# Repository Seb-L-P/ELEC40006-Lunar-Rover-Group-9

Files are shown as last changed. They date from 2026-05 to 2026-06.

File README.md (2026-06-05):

# EEELunarRover - Group 9

ELEC40006 Electronics Design Project. A remotely operated lunar rover that drives across an arena and classifies rocks by their age and type.

## Repository layout

| Path | What it is |
| --- | --- |
| `rover_firmware/` | Metro M0 firmware: WiFi HTTP server, motor control, sensor hooks |
| `UI/` | Browser-based operator console (HTML/CSS/JS) plus a mock rover server |
| `hardware/` | Component datasheets, the pin map, and the **[bill of materials](hardware/BOM.md)** |
| `mech/` | **[Rover layout, 3D-printed sensor mounts, and what to order](mech/README.md)** |
| `CONTROLLER_PLAN.md` | HTTP API contract and controller subsystem design |
| `PROJECT_SUMMARY.md` | Project brief, objectives, constraints, rock classification |

The operator control and firmware are built and hardware-tested. The four analogue sensor subsystems (radio, infrared, ultrasound, magnetic) are in progress by other group members and plug into the firmware through its `readX()` hooks.

## How it works

The operator runs the console in a browser. It talks to the rover over WiFi using a small HTTP API:

```text
Operator browser  <--- WiFi / HTTP --->  Metro M0 firmware
   (UI/)                                  (rover_firmware/)
                                               |
                                       motors and sensors
```

The firmware exposes five endpoints (`/info`, `/status`, `/drive`, `/stop`, `/scan`). The UI polls `/status` for telemetry, sends `/drive` to move the rover, and `/scan` to classify a rock. The full contract is in `CONTROLLER_PLAN.md`.

## Quick start

### Operator console (no hardware needed)

```bash
cd UI
python3 mock_server.py
```

Open <http://localhost:8080/>. The mock server simulates a rover so the UI can be developed and tested without any hardware.

### Firmware

Open `rover_firmware/` in VS Code with the PlatformIO extension, or from the command line:

```bash
cd rover_firmware
pio run            # build
pio run -t upload  # flash a connected Metro M0
```

## Status

| Part | State |
| --- | --- |
| Firmware build | Compiles; runs on real Metro M0 hardware |
| HTTP API | All five endpoints verified over WiFi |
| Drive control | Verified end to end, operator console to motors |
| Operator UI | Working; gamepad, keyboard and on-screen control |
| Sensors | Stubbed; awaiting the four analogue subsystems |

See `rover_firmware/TEST_LOG.md` for the detailed hardware test record.

## Rock classification

The rover identifies one of four rock types from three measurements:

| Type | Infrared rate | Ultrasound | Magnet |
| --- | --- | --- | --- |
| Basaltoid | high (~547/s) | present | down |
| Gravion | low (~312/s) | absent | down |
| Regolix | low (~312/s) | present | up |
| Lunarite | high (~547/s) | absent | up |

It also reads the rock's age, transmitted by radio. Full detail in `PROJECT_SUMMARY.md`.

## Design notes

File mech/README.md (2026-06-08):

# Mechanical & sensor layout — rover design, 3D prints, and parts to order

This folder is the **mechanical/sensor design package**: where every sensor,
the battery and the boards sit on the rover, the 3D-printable mounts that hold
them, and **exactly what we need to order** (with supplier links and prices).

- 📐 Full design rationale + diagrams → **[`rover_layout.md`](rover_layout.md)**
- 🧾 Full bill of materials + ordering rules → **[`../hardware/BOM.md`](../hardware/BOM.md)**
- 🖨️ How to print the parts → **[`print/README.md`](print/README.md)**
- 🧱 Alternative **stacked-deck chassis** concept (two decks on pillars + coil ring) → **[`stacked_deck/`](stacked_deck/README.md)**

## The whole rover

| Isometric | Top-down (layout) |
|---|---|
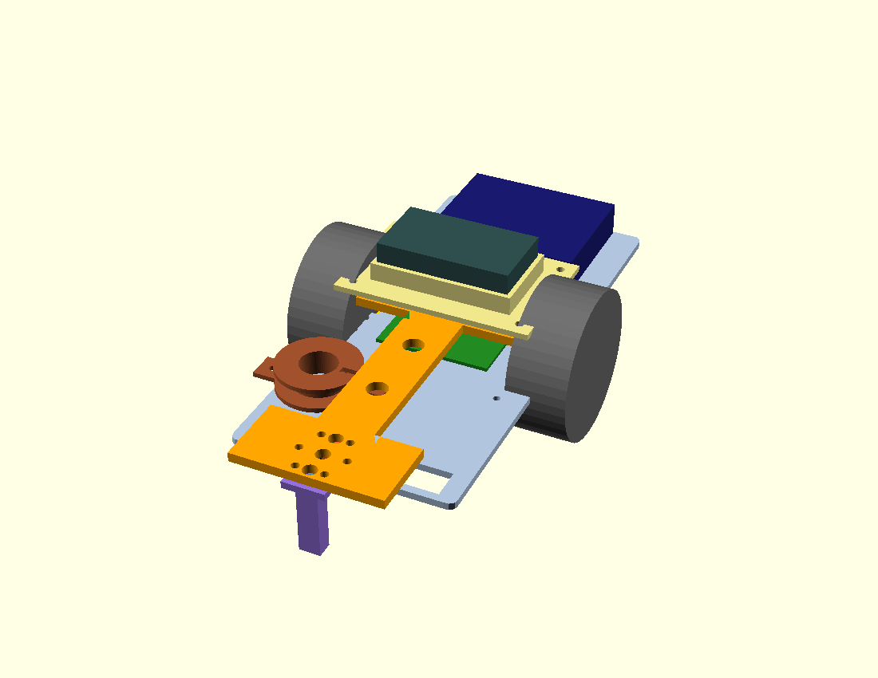
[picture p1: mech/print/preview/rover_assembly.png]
rover assembly
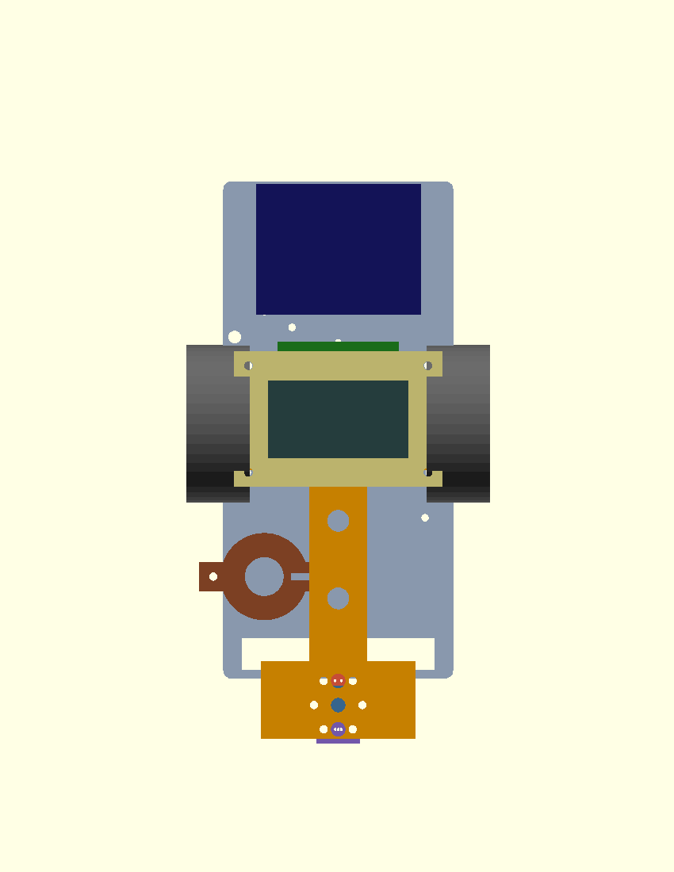
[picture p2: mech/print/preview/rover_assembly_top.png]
rover top view
|  |  |

*The chassis, wheels, battery and Metro are representative blocks; the boom,
sensor housings and battery tray are the actual printable parts. Open
`print/rover_assembly.scad` in OpenSCAD (press F5) to spin it around.*

## Design in brief

The EEEBug is a **centre-axle** rover (it pivots about the middle), so:

- **Sensors go on a front boom**, as far as possible from the motor magnets and
  PWM noise — the **Hall sensor** especially, on a long pod that reaches near the
  floor to read the magnet inside the rock.
- **IR, ultrasound and Hall** face **down** in a line at the boom tip; the rover
  noses up to a rock and scans it.
- **Radio antenna coil** sits low at the **front-left**, off the boom centre-line.
- **Battery (4×AA, ~100 g)** sits on a tray **over the axle** — balances the
  pivot, loads the wheels for traction, and keeps its noise away from the weak
  analogue front-ends.
- **Metro M0 + WiFi** stay at the **rear**.
- Estimated total mass **≈ 503 g** (limit 750 g); design spend **≈ £20–51**
  (budget ~£55). See the layout doc for the full weight budget and rationale.

## What's in here

| File | What it is |
|---|---|
| [`rover_layout.md`](rover_layout.md) | Master design doc: layout, physics rationale, weight budget, keep-out zones, hole mapping, assembly order |
| [`../hardware/BOM.md`](../hardware/BOM.md) | Full parts list with supplier order codes, prices, dimensions, ordering rules |
| [`print/`](print/README.md) | Parametric OpenSCAD parts (`.scad`), rendered `.stl`, preview `.png`, and `render.sh` |
| `print/rover_assembly.scad` | The whole-rover 3D model (visualisation) |
| `print/chassis.scad` | Exact EEEBug outline auto-generated from `chassis.svg` |
| `chassis.svg` / `.dxf` / `.pdf` | Original EEEBug V3.1 chassis CAD (laser-cut source) |
| [`CHASSIS_CAD.md`](CHASSIS_CAD.md) | Notes on the chassis CAD formats / laser-cut conventions |

Printable parts: `boom`, `ir_shroud`, `ultrasound_clamp`, `hall_pod`,
`antenna_bobbin`, `perfboard_carrier`, `battery_tray`. All print flat in PLA,
no supports; largest is the boom at 86 × 127 mm (well inside the 200 mm printer).

---

## 🛒 Parts to order

> **Orders go through the [EEE Stores order form](https://www.imperial.ac.uk/electrical-engineering/internal/stores/)** via our nominated approver.
> Allowed suppliers only (RS / OneCall = Farnell & CPC / Rapid / EED Stores).
>
> ⚠️ **Prices are estimates** — the supplier pages block automated price
> reads, so **click the link and confirm the live price on the order form
> before ordering.** Order codes and dimensions are datasheet/catalogue-verified.
>
> 🚫 Per the brief: **do not order batteries, glue/chemicals, or tools.** The AA
> cells, magnet, Metro, WiFi shield, motor driver and breadboard are in the kit.
> Everything below is **through-hole** (no surface-mount).

### Group A — specialist sensor parts (order from RS / Farnell / CPC)

| Part | For | Supplier · code | Qty | Unit (est) | Line (est) |
|---|---|---|---|---|---|
| Murata **MA40S4R** 40 kHz Rx | ultrasound | [CPC SN36522](https://cpc.farnell.com/murata/ma40s4r/sensor-ultrasonic-0-2-4m-rx/dp/SN36522) | 2 | £2.50 | £5.00 |
| Honeywell **SS49E** Hall | magnetic | [RS 236-2760](https://uk.rs-online.com/web/p/hall-effect-sensors/2362760) | 2 | £1.50 | £3.00 |
| OSRAM **SFH 300** phototransistor | infrared | [Farnell 2981724](https://uk.farnell.com/osram-opto-semiconductors/sfh-300/photo-trans-npn-880nm-radial-leaded/dp/2981724) | 2 | £0.60 | £1.20 |
| Microchip **MCP6292-E/P** dual op-amp (DIP-8) | IR/radio/US amps | [Farnell 1439466](https://uk.farnell.com/microchip/mcp6292-e-p/op-amp-10mhz-dual-pdip8-6292/dp/1439466) | 3 | £1.00 | £3.00 |
| Roth **RE016-LF** perfboard (68.6×68 mm) | large board | [RS 897-1402](https://uk.rs-online.com/web/p/matrix-boards/8971402) | 1 | £3.39 | £3.39 |
| Roth **RE015-LF** perfboard (40.5×40 mm) | small boards | [RS 897-1408](https://uk.rs-online.com/web/p/matrix-boards/8971408) | 2 | £1.63 | £3.26 |
| | | | | **Subtotal A** | **≈ £18.85** |

### Group B — commodity parts (try EED Stores dept stock first, else order)

| Part | For | Supplier · code | Qty | Unit (est) | Line (est) |
|---|---|---|---|---|---|
| M3 nylon hex standoff, M-F, 15 mm (pk 100) | mount boom/tray | [Rapid 52-4352](https://www.rapidonline.com/r-tech-524352-nylon-hexagonal-m3-m-f-spacers-15mm-pack-of-100-52-4352) | 1 | £7.63 | £7.63 |
| M3 steel pan screw, 6 mm (pk 100) | board/module screws | [Rapid 33-7089](https://www.rapidonline.com/r-tech-337089-pozi-pan-head-a2-stainless-steel-screws-m3-6mm-pack-of-100-33-7089) | 1 | £4.59 | £4.59 |
| M3 steel hex nut (pk 100) | lock standoffs | [Rapid 33-7173](https://www.rapidonline.com/r-tech-337173-a2-stainless-steel-hex-nut-m3-pack-of-100-33-7173) | 1 | £3.89 | £3.89 |
| Enamelled copper wire 0.28 mm (solderable) | 89 kHz antenna coil | [RS 779-0700](https://uk.rs-online.com/web/p/copper-wire/7790700) | 1 | £8–12 | £10.00 |
| 0.1″ pin headers + M-M jumper leads | inter-board wiring | CPC / dept stock | – | £3.00 | £3.00 |
| Resistors + capacitors (IR/radio/US front-ends) | front-ends | dept stock / kit | – | £3.00 | £3.00 |
| | | | | **Subtotal B** | **≈ £32.11** |

**Budget:** ≈ **£51 if everything is ordered**, or **≈ £20–25** if Group B comes
from EED Stores dept stock — both inside the ~£55 left. See
[`../hardware/BOM.md`](../hardware/BOM.md) for spare quantities, the SS495A (5 V)
Hall alternative, and the full ordering-rules checklist.

---

## See / build it

- **3D model:** open `print/rover_assembly.scad` in [OpenSCAD](https://openscad.org) → press **F5** (drag to rotate). Or just look at the PNGs in `print/preview/`.
- **Print:** `cd mech/print && ./render.sh` regenerates all STLs; print PLA, 0.2 mm layers, 4 perimeters, 25 % infill, no supports.
- **Edit a dimension:** every part is parametric — change the variable at the top of the relevant `.scad` (e.g. battery-pocket size in `battery_tray.scad`).

*Questions on this design → ask in the group chat or open an issue.*

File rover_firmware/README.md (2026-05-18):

# EEELunarRover Firmware

Metro M0 Express + WINC1500 WiFi shield. Implements the HTTP API contract in `../CONTROLLER_PLAN.md`, drives the H-bridge motor module, and exposes stubs that each sensor subsystem owner replaces with real hardware code.

## Build and flash

Two routes, both target the same `src/main.cpp`.

### PlatformIO (recommended)

1. Install [VS Code](https://code.visualstudio.com/) and the [PlatformIO extension](https://platformio.org/install/ide?install=vscode).
2. Open this `rover_firmware/` folder.
3. Plug the Metro M0 into the laptop via USB.
4. Click the **Build** (✓) and then **Upload** (→) buttons in the bottom toolbar, or run from the integrated terminal:

   ```bash
   pio run                 # build
   pio run -t upload       # flash
   pio device monitor      # serial monitor at 9600 baud
   ```

PlatformIO will download the SAMD platform, ArduinoJson, and WiFiWebServer on the first build.

### Arduino IDE

Copy the contents of `src/main.cpp` into a sketch called `EEELunarRover.ino` and install:

- Board support: follow [Adafruit's Metro M0 setup guide](https://learn.adafruit.com/adafruit-metro-m0-express/arduino-ide-setup).
- Libraries (via Library Manager): **WiFiWebServer** (Khoi Hoang) and **ArduinoJson** (Benoit Blanchon, v6.x).

## What to change before first flash

Open `src/main.cpp` and review the **Configuration** block near the top:

| Constant | Default | Set to |
| --- | --- | --- |
| `ssid` / `pass` | `EEERover` / `exhibition` | Lab WiFi credentials. Override if testing on a hotspot. |
| `groupNumber` | `0` | Your group number. This sets a static IP of `192.168.0.<groupNumber+1>` on the lab network. |
| `LEFT_DIR_PIN`, `LEFT_PWM_PIN`, `RIGHT_DIR_PIN`, `RIGHT_PWM_PIN` | `12`, `6`, `4`, `9` | Set to the current dual H-bridge wiring (see `../hardware/pin_map.md`). Change only if the rover is rewired. **Avoid 5, 7, 10** (reserved by the WiFi shield). |
| `DRIVE_WATCHDOG_MS` | `500` | Time without a `/drive` heartbeat before motors auto-stop. Don't reduce below the UI heartbeat interval (150 ms) plus margin. |
| `SCAN_DURATION_MS` | `600` | Window over which `/scan` integrates measurements. Increase to count more IR pulses for better Poisson rate discrimination. |

## Verifying it works

After flashing, open the serial monitor at 9600 baud. You should see:

```text
EEELunarRover firmware starting
Connecting to EEERover
.....
IP: 192.168.0.<your_ip>
HTTP server running
```

Then on a laptop or phone on the **same WiFi network**:

```bash
# Replace the IP with whatever the serial monitor reported
curl http://192.168.0.1/info
curl http://192.168.0.1/status
curl "http://192.168.0.1/drive?l=128&r=-64"
curl http://192.168.0.1/stop
curl http://192.168.0.1/scan
```

Each should return a JSON document. The onboard LED reports status: **fast blink** while WiFi is down, **solid** when `/drive` is driving the motors, **off** when idle and connected. So even with no serial cable attached, a fast-blinking LED means "not on WiFi" and a solid LED means "receiving drive commands".

To connect the operator UI, open it with the rover's IP in the API query string:

```
http://localhost:8080/?api=http://192.168.0.<groupNumber+1>
```

(The mock server at `../UI/mock_server.py` is no longer needed once real firmware is running, but you can still serve the UI files with it if you prefer.)

## Plugging in real sensors

Inside `src/main.cpp`, find the section labelled **Sensor stubs (to be replaced)**. Each function returns fake but plausible data so the UI runs end-to-end before any analogue hardware exists.

When a sensor subsystem is ready, replace the body of the corresponding function while keeping its return shape identical:

| Function | Owner | Returns |
| --- | --- | --- |
| `readAge()` | Radio subsystem | `{ "#NNN", valid }` |
| `readIR()` | IR subsystem | `{ pulses-per-second, valid }` |
| `readUltrasound()` | Ultrasound subsystem | `{ present (bool), valid }` |
| `readMagnet()` | Magnet subsystem | `{ "up" \| "down", valid }` |
| `readBatteryMv()` | Anyone | int millivolts |

Each sensor owner should be able to develop their function in isolation, hand it over, and have it Just Work without touching the routing or JSON code.

## Architecture notes

- **Why a 500 ms watchdog.** If WiFi drops while a drive key is held, the motors would keep running until the laptop reconnected. The watchdog auto-stops the rover instead. The UI sends `/drive` heartbeats every 150 ms while a key is pressed, which is well inside the watchdog window.
- **Why JSON for `/status`.** Slightly fatter on the wire than a delimited string but trivially parsed in the browser and self-describing for debugging.
- **Why `/scan` blocks.** Single-threaded server, simplest implementation. The UI shows a "Scanning..." button state during the ~600 ms scan and resumes polling afterwards. A more advanced version could integrate IR pulse counts asynchronously.
- **Why classification is not on the rover.** The UI does the table lookup. Keeps the firmware simpler and lets us tweak rules without re-flashing. See section 4.1 of `../CONTROLLER_PLAN.md`.
- **Why CORS headers.** The UI is hosted on the operator's laptop during development, which is a different origin from the rover's IP. The `Access-Control-Allow-Origin: *` header on every JSON response lets the browser accept the response.
- **Why the WiFi connect is bounded and retried.** The starter sketch loops on `WiFi.begin()` forever; a bad password or absent network hangs the board silently. This firmware tries a bounded number of times, then starts anyway and keeps retrying from `loop()`. If the link drops mid-demo it stops the motors and reconnects on its own.
- **Why JSON serialises into a fixed buffer.** Building a heap `String` per request would fragment the 32 KB RAM over a long run. A fixed stack buffer avoids that.

## Files

```text
rover_firmware/
├── platformio.ini       PlatformIO project config + library deps
├── README.md            this file
└── src/
    └── main.cpp         all the firmware in one file, sectioned by purpose
```

The single-file structure is intentional. The codebase is small enough that splitting into headers would add navigation overhead without saving lines. As each sensor owner adds non-trivial logic, they may choose to factor their code into `src/sensor_<name>.cpp` and an `include/sensor_<name>.h` - PlatformIO will pick those up automatically.

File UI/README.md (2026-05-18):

# Operator UI

Static HTML/JS/CSS operator interface for the EEELunarRover. Talks to the rover over HTTP per the contract in `../CONTROLLER_PLAN.md`.

## Run it locally (mock mode)

The mock server hosts the UI and a fake rover API on the same port, so no CORS pain.

```bash
cd UI
python3 mock_server.py
```

Then open <http://localhost:8080/> in a browser. The simulated rock changes every time you press **Scan rock**.

Requires Python 3.7+. No pip install needed, only the standard library.

## Run against a real rover

Open the page against the rover's HTTP server. Two ways:

1. **UI served by the rover firmware** (if the embedded lead implements `GET /` to return this `index.html`): just visit `http://192.168.0.<groupNumber+1>/`.
2. **UI hosted on your laptop, API on the rover:** open `http://localhost:8080/?api=http://192.168.0.<groupNumber+1>` so the page fetches from the rover instead of localhost. Requires the firmware to send `Access-Control-Allow-Origin: *` headers, or visit the page directly from the rover.

## Controls

The console accepts three input methods, all live at once:

### Gamepad (primary)

Pair an Xbox (or any standard) controller with the laptop over USB or Bluetooth. The browser detects it automatically via the Gamepad API; the header shows "Gamepad connected".

| Control | Action |
| --- | --- |
| Left stick | Drive (proportional speed and turn) |
| Controller D-pad | Drive (digital) |
| A button | Scan rock |
| B button | Stop |

The left stick wins whenever it is moved; release it and keyboard/on-screen control takes over.

### Keyboard and on-screen D-pad (fallback)

Always available, including if the gamepad disconnects mid-run.

| Key | Action |
| --- | --- |
| `W` / `↑` | Forward (hold) |
| `S` / `↓` | Reverse (hold) |
| `A` / `←` | Turn left (hold) |
| `D` / `→` | Turn right (hold) |
| `Space` / `X` / `Esc` | Stop |

The on-screen mini D-pad in the Control panel does the same thing for touch/mouse.

Switching tab or backgrounding the page auto-sends `/stop` for safety.

## Files

| File | Purpose |
| --- | --- |
| `index.html` | Page structure |
| `styles.css` | Layout and theme |
| `app.js` | Input handling, polling, classification, scan, saved readings |
| `mock_server.py` | Local rover stand-in implementing the same HTTP API |

## Classification logic

Lives in `app.js` (`classify()`) as a four-row lookup against the table in the project brief:

| IR rate (Hz) | Ultrasound | Magnet | Type |
| --- | --- | --- | --- |
| ≥ 430 (≈547) | present | down | Basaltoid |
| < 430 (≈312) | absent | down | Gravion |
| < 430 (≈312) | present | up | Regolix |
| ≥ 430 (≈547) | absent | up | Lunarite |

The 430 Hz threshold is the midpoint between the two Poisson rates (312 and 547 s⁻¹). The brief warns to expect small deviations, hence the wide margin.

## What this UI assumes from the firmware

- `GET /info` returns JSON with `group`, `ip`, `fw_version`.
- `GET /status` returns the JSON shape used by `renderStatus()` in `app.js`.
- `GET /drive?l=<int>&r=<int>` accepts signed PWM values in `[-255, 255]`.
- `GET /stop` zeroes both motors immediately.
- `GET /scan` runs a measurement cycle (≤ ~1 s) and returns age + raw sensor readings.
- A **500 ms watchdog** auto-zeros motors if `/drive` stops being called. The UI re-sends the held command every 150 ms to stay inside the watchdog.

All of this is locked in `../CONTROLLER_PLAN.md` and must be agreed with the embedded lead before code on either side hardens.

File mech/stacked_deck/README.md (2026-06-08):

# Stacked-deck chassis + coil support

An alternative chassis concept (inspired by the reference rover): **two
rectangular decks with the board's hole pattern, stacked on 4 corner pillars**,
plus a **braced coil ring + sensor tray** that screws onto a deck.

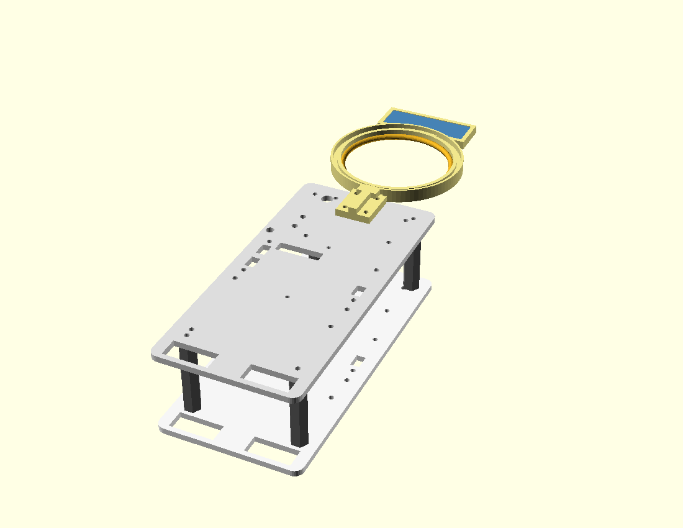
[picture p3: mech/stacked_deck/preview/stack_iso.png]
assembly


## One STL per component

| STL | Print qty | Size | Notes |
|---|---|---|---|
| `stl/deck_half_A.stl` | ×2 | ~122 × 95 mm | front half + bottom overlap ledge (motor slots) |
| `stl/deck_half_B.stl` | ×2 | ~102 × 95 mm | rear half + top overlap ledge (**print upside-down**) |
| `stl/pillar.stl` | ×4 | Ø10 × 50 mm | corner stacking pillar (~5 cm deck gap) |
| `stl/coil_support.stl` | ×1 | ~127 × 91 mm | braced ring (coil) + perfboard tray |
| `stl/deck_full.stl` | — | 204 × 95 mm | **reference/viewing only — too long to print whole** |

A full deck is **204 mm**, longer than the 200 mm printer, so each deck prints
as **half A + half B** (both inside the ~15–18 cm target) that **overlap** at a
half-lap and bolt together. Two identical decks → **either board can be on top**.

## How the parts connect

| Pillar ↔ decks | Half A ↔ half B |
|---|---|
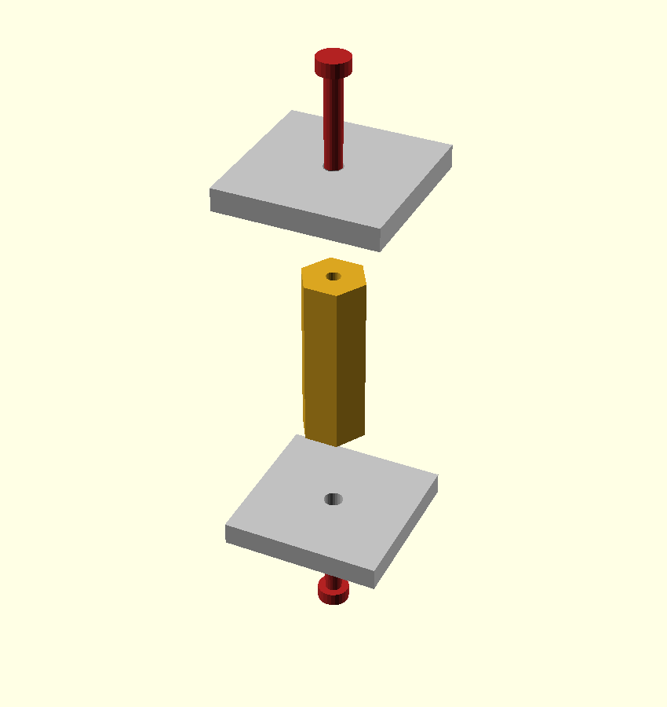
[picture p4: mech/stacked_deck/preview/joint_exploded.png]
pillar joint
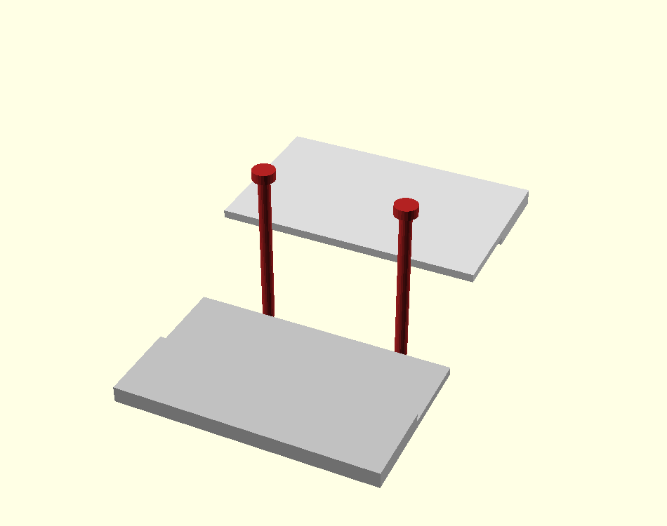
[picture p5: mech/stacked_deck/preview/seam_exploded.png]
seam joint
|  |  |
| A short M3 screw through each deck's corner hole self-taps into the pillar end. | The two halves **overlap** (half-lap) and 2 M3 screws clamp them into one flush deck — no extra part. |

## How it goes together

1. Overlap `deck_half_A` (front) and `deck_half_B` (rear) at the half-lap and
   clamp with 2 M3 screws (+ nuts) → one flush deck. Do it twice.
2. Stand the **4 pillars** between the decks at the corner holes. Drive a short
   **M3 × 8–10 mm screw through each deck's corner hole into the pillar end** —
   it self-taps into the pillar's Ø2.5 pilot and clamps the deck. (Sturdier
   option: one M3 threaded rod through deck+pillar+deck with a nut each end —
   set `HOLE = M3_CLEAR` in `pillar.scad`.)
3. Screw the **coil support** onto a deck's 4 coil-mount holes (4× M3). The coil
   (~75 mm) drops into the ring and is held by the lip; the **braced rim** stops
   the arm drooping.
4. Mount your **60 × 20 mm perfboard** (ultrasound + phototransistor) in the
   tray; the sensors face **down** through the slot.

## Key parameters (all at the top of each `.scad`)

| What | Value | File |
|---|---|---|
| Coil diameter | 75 mm (set yours: 70–75) | `coil_support.scad` `COIL_D` |
| Deck spacing (pillar height) | 50 mm (~5 cm) | `pillar.scad` `PILLAR_H` |
| Brace height | 9 mm | `coil_support.scad` `H_BRACE` |
| Deck thickness | 4 mm | `deck.scad` `DECK_T` |
| Coil support on which deck | upper (sensors up top) | `stack_assembly.scad` `sup_z` |

## Notes / honest flags
- **Sensors are on the top deck** (as requested) — ~50 mm higher off the ground,
  so the down-facing sensors have a bigger gap to the rock. Drop `sup_z` to the
  lower deck if scanning range matters more than the top mount.
- **Weight:** two 4 mm PLA decks + pillars + support ≈ **120–140 g**. If the
  750 g limit gets tight, thin the decks to 3 mm or add lightening cut-outs.
- **Cantilever:** the support reaches ~110 mm past the deck edge. The brace
  handles droop; for extra security add a small skid leg under the tray tip.

## View it
Open `stack_assembly.scad` in OpenSCAD → **F5** (drag to rotate), or see
`preview/stack_iso.png`. Re-render all STLs from the `.scad` files with OpenSCAD.

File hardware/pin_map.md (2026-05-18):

# Pin Map

Metro M0 pin assignments for the EEELunarRover.

## Reserved by the WINC1500 WiFi shield

Pins **5, 7, 10** (CS, IRQ, RST). Do not use these for anything else.

## Motor driver (dual H-bridge)

Each motor has a direction line and an enable line; the enable line carries the PWM speed signal.

| Signal | Metro pin |
| --- | --- |
| Left motor direction | D12 |
| Left motor enable (PWM) | D6 |
| Right motor direction | D4 |
| Right motor enable (PWM) | D9 |

These match the constants in `../rover_firmware/src/main.cpp`. Verified on hardware: motors driven over WiFi from the operator console.

## Sensors

To be assigned as each analogue subsystem is built. Keep clear of pins 5, 7, 10. Pin 0 (UART RX) is the natural choice for the radio subsystem's decoded serial input.

| Subsystem | Metro pin | Notes |
| --- | --- | --- |
| Radio (age) | D0 (UART RX) | suggested; receives the demodulated UART signal |
| Infrared | TBD | |
| Ultrasound | TBD | |
| Magnetic | TBD | |

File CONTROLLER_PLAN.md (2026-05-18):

# Controller Subsystem Plan

**Owner:** [User's name] - UI / web controller
**Embedded counterpart:** [Teammate's name] - Metro M0 firmware
**Status:** Draft v0.1 - to be reviewed by the team
**Last updated:** 2026-05-13

This document defines the operator UI, the HTTP API between the UI and the rover, and the working agreement between the **UI lead (me)** and the **embedded lead** (teammate writing the Metro M0 firmware).

It is deliberately written *before* any code so that both sides can develop in parallel against the same contract. Once it's agreed, neither side should change the contract unilaterally.

---

## 1. Goals

The controller subsystem must let an operator:

1. **Drive** the rover around the arena with low enough latency that it feels responsive.
2. **See live sensor data** from every subsystem (radio age, IR pulse rate, ultrasound, magnet).
3. **See the classification** of the rock currently in front of the rover (Basaltoid / Gravion / Regolix / Lunarite).
4. **Recover gracefully** when WiFi drops, the rover is rebooting, or a sensor isn't ready.

Non-goals (out of scope for the project):

- Multi-user operation (one operator at a time).
- Persistent storage of past runs (a CSV download is nice-to-have, not required).
- Offline mode.

---

## 2. Architecture

```text
+----------------------+       WiFi (HTTP)        +-----------------------------+
|  Operator browser    | <----------------------> |  Metro M0 firmware          |
|  (laptop or phone)   |   GET /status, /drive,   |  WiFiWebServer @ 192.168... |
|  Static HTML/JS/CSS  |   /scan, /stop           |                             |
+----------------------+                          +-----------------------------+
                                                       |        |        |
                                                  motors   sensor MCU pins
```

**Decision:** the UI is a **static HTML/JS/CSS page hosted on the operator's laptop** (or served by the Metro for fallback). It talks to the Metro via HTTP. This means:

- The UI can be developed and tested against a **mock server on the laptop** without needing a real rover. Critical for parallel work.
- The Metro firmware only has to serve a small JSON API, not a webpage with embedded HTML/JS. Shorter firmware, less re-flashing.
- At demo time the laptop runs a browser pointed at `http://192.168.0.<groupNumber+1>/`.

**Fallback:** if the laptop's WiFi can't reach the rover, the firmware also serves a minimal HTML page at `GET /` so the operator can drive from a phone on the lab WiFi.

---

## 3. HTTP API Contract (v0.1)

All endpoints return `Content-Type: application/json` unless noted. All responses include a `t` field with the rover's uptime in milliseconds (`millis()`).

Errors return HTTP 4xx/5xx with `{"error": "<message>"}`.

### 3.1 Status & telemetry

#### `GET /status`

Polled by the UI at ~5 Hz. Returns the latest snapshot of everything.

```json
{
  "t": 12345,
  "drive": { "left": 128, "right": -64 },
  "sensors": {
    "age": "#317",
    "age_valid": true,
    "ir_rate_hz": 547,
    "ir_valid": true,
    "ultrasound_present": true,
    "ultrasound_valid": true,
    "magnet": "up",
    "magnet_valid": true
  },
  "battery_mv": 7200,
  "state": "idle"
}
```

- `age` is the 4-character string received over radio (`#NNN`), or `null` if not yet decoded.
- `*_valid` flags let the UI grey out stale readings instead of showing rubbish.
- `state` is `idle | driving | scanning | error`.

#### `GET /info`

Returns once at UI startup.

```json
{ "group": 7, "ip": "192.168.0.8", "fw_version": "0.1.0" }
```

### 3.2 Driving

#### `GET /drive?l=<int>&r=<int>`

Sets the left and right motor commands. Both are signed integers in `[-255, 255]`. `0` = stop. Sign = direction. Magnitude maps to PWM duty.

Response: `200 OK` with `{ "t": ..., "drive": { "left": l, "right": r } }`.

**Watchdog:** if the firmware doesn't receive a `/drive` call for **500 ms**, it must automatically set both motors to 0. This prevents runaway if WiFi drops while a button is held.

#### `GET /stop`

Hard stop - sets both motors to 0 immediately, returns `{ "t": ..., "stopped": true }`.

### 3.3 Scanning

#### `GET /scan`

Triggers a measurement cycle. The firmware:

1. Reads each sensor for up to ~1 second.
2. Decodes the age from the radio buffer.
3. Returns a result snapshot.

```json
{
  "t": 12500,
  "age": "#317",
  "ir_rate_hz": 547,
  "ultrasound_present": true,
  "magnet": "up",
  "classification": null
}
```

`classification` is left `null` here - **classification is done on the UI side** (see the next section), so the UI does the table lookup using the four raw values.

---

## 4. What lives where

Two parallel "where does this logic run" decisions.

### 4.1 Classification logic, UI side

**Decision:** classification (mapping {IR rate, ultrasound, magnet} to rock type) lives **in the JS on the UI side**, not in the firmware.

**Why:**

- The rules can change without re-flashing the Metro.
- The UI can show *why* a rock was classified the way it was ("547 Hz IR + ultrasound + up = Regolix").
- Firmware stays simpler, it returns raw measurements.

**Trade-off:** if we ever wanted a "lights-only" UI (no JS) it wouldn't work. Acceptable, we always have JS at demo time.

### 4.2 State machine, firmware side

**Decision:** the rover state machine (`idle | driving | scanning | error`) lives **in the firmware**. The UI mirrors it by rendering whatever `/status.state` reports.

**Why:**

- Every state transition is triggered by something only the firmware can observe: a `/drive` request arrived, the 500 ms watchdog fired, a scan finished, a sensor faulted.
- One source of truth. If the UI also tracked state, a WiFi blip or a page refresh would put UI and rover out of sync and recovery would be subtle.
- Recovery is automatic, the UI just renders whatever the next `/status` reports.

The UI keeps its own **view state**, which is presentation-only and never round-trips to the firmware:

- `connecting...` (no `/status` response yet)
- `stale` (last `/status` older than 1 s)
- modal open/closed, speed slider position, saved-readings panel state.

**Rule of thumb when in doubt:** if the value would need to survive an unplug-and-reboot of the rover, it is rover state and lives in the firmware. If not (slider position, modal open/closed), it is view state and lives in the UI.

---

## 5. UI scope (this is mine)

### 5.1 Screen layout (rough)

Drive controls are the focal point - large D-pad style buttons, big central STOP, prominent speed slider. Sensors and classification sit in a slimmer right-hand column so the operator's eye and thumb both default to the drive panel during a run.

```text
+------------------------------------------------------------------------------+
|  EEELunarRover Operator                                     [ status dot ]   |
+------------------------------------------------------------------------------+
|                                                                              |
|   +----- DRIVE -----------------------+    +--- Sensors -----------------+   |
|   |                                   |    | Age:         #317           |   |
|   |              +-----------+        |    | IR rate:     547 Hz         |   |
|   |              |    /\     |        |    | Ultrasound:  present        |   |
|   |              |  FORWARD  |        |    | Magnet:      up             |   |
|   |              +-----------+        |    +-----------------------------+   |
|   |                                   |                                      |
|   |  +-------+  +----------+ +------+ |    +--- Classification ----------+   |
|   |  |  <-   |  |          | |  ->  | |    |  ROCK TYPE:  Regolix        |   |
|   |  | LEFT  |  |   STOP   | | RIGHT| |    |  Age:        3.17 Gyr       |   |
|   |  +-------+  |   [ X ]  | +------+ |    +-----------------------------+   |
|   |             |          |          |                                      |
|   |             +----------+          |    +--- Actions -----------------+   |
|   |                                   |    |  [   Scan rock   ]          |   |
|   |              +-----------+        |    |  [   Save reading ]         |   |
|   |              |   \/      |        |    +-----------------------------+   |
|   |              |  REVERSE  |        |                                      |
|   |              +-----------+        |                                      |
|   |                                   |                                      |
|   |   Speed  [============O=========] |                                      |
|   |          slow              fast   |                                      |
|   |                                   |                                      |
|   |   Keys: W / A / S / D or arrows   |                                      |
|   +-----------------------------------+                                      |
|                                                                              |
+------------------------------------------------------------------------------+
```

Notes on the layout:

- Drive panel occupies ~60% of the page width and stays fixed in place - the operator never has to scroll to reach a control.
- **STOP** is the only red button on the page and is the biggest target. It triggers `GET /stop` and overrides any held drive button.
- Directional buttons use both an arrow glyph **and** a word so the meaning is unambiguous on a phone or to someone new to the UI.
- Speed slider labels the extremes (`slow` / `fast`) and shows a live numeric readout above the bar (not drawn).
- Keyboard hint is rendered inside the drive panel so it's discoverable.

### 5.2 Controls

- **Driving:** on-screen buttons + WASD/arrow-key fallback. Hold = drive, release = stop (relies on the firmware watchdog defined in the Driving endpoint above).
- **Speed slider** caps max PWM so testing isn't terrifying.
- **STOP** is a hard stop - calls `GET /stop`, cancels any held direction.
- **Scan button** calls `/scan` and renders the result + classification.
- **Save reading** appends the current scan to a local CSV-like list in `localStorage` (nice-to-have).

### 5.3 Tech choices

- Plain **HTML + CSS + vanilla JS**. No build step. One `index.html`, one `app.js`, one `styles.css`.
- A `MOCK = true` flag in `app.js` that swaps `fetch('/status')` for a local fake-data function - so I can develop with no rover at all.

---

## 6. Liaison plan with the embedded lead

This is the part that has to actually work.

### 6.1 Division of labour

| Area | Owner |
| --- | --- |
| WiFi setup, HTTP server, JSON serialisation | Embedded |
| Motor PWM (using H-bridge module, DIR/PWM pins) | Embedded |
| `/drive` watchdog (500 ms timeout) | Embedded |
| Sensor reading code per subsystem | **Each sensor owner** writes a function (`readIR()`, `readMagnet()`, etc.) that the embedded lead calls from `/status` and `/scan` |
| `/status` JSON shape | **Both**: locked by the API contract above |
| HTML page (`GET /`) fallback for phone driving | Embedded (minimal - just buttons calling `/drive`) |
| Full UI (rich JS app) | Me |
| Classification table-lookup | Me (in JS) |
| Mock server for local UI development | Me |

### 6.2 Working agreement

1. **The API contract (§3) is the source of truth.** Any change is a 2-minute conversation between me and the embedded lead, then both sides update.
2. **Shared git repo** for the firmware *and* the UI - branches per feature, PRs for review (and so the rest of the team can see progress).
3. **Weekly 15-minute sync** between me and the embedded lead. Just us, separate from the team standup.
4. **One Slack/Teams channel** for the two of us so quick API questions don't get buried in the group chat.
5. **Both sides keep a stub of the other.** Firmware ships with a hardcoded fake `/status` from day one. UI ships with a `MOCK = true` mode from day one. Neither subsystem is allowed to block the other.

### 6.3 Integration milestones

| Date | Embedded ships | I ship | Joint test |
| --- | --- | --- | --- |
| **2026-05-16** | Starter sketch flashed, web server reachable on the lab WiFi, `GET /info` returns hardcoded JSON | UI loads in mock mode, drive buttons + sensor panels render with fake data | Browser on the lab WiFi can reach `/info` on the Metro |
| **2026-05-20** | `/status` returns hardcoded JSON matching the contract above; `/drive` toggles a debug LED | UI driving buttons hit `/drive`; UI polls `/status` at 5 Hz and shows the fake values | End-to-end click → LED, with sensor panel updating from hardcoded JSON |
| **2026-05-25** | `/drive` actually drives the motors with watchdog; one real sensor (say magnet) wired into `/status` | Classification logic in JS, scan flow works end-to-end with mock + real magnet | Drive the rover on a bench, scan a real magnet, see "up/down" in the UI |
| **2026-05-27** | Whatever sensors are working integrated into `/status` and `/scan` | Polished UI for interim demo | Dress rehearsal for **interim 2026-05-28** |

### 6.4 Things I need from the embedded lead

- Group number (so I know the static IP).
- Confirmation of the API contract in §3 - or proposed changes.
- A debug pin/LED I can toggle via `/drive` before motors are wired.
- Their preferred git workflow (single repo with `rover_firmware/` + `UI/` folders? two repos?).

### 6.5 Things they need from me

- A working **mock server** (`mock_server.py`) so they can test their UI HTML fallback against the same JSON shapes I'm consuming.
- A short list of HTTP behaviours the firmware must implement (the watchdog, the error JSON shape, the auto-stop on missing `/drive` heartbeats). Already captured above.

---

## 7. Open questions for the team

Decisions that affect more than just the controller subsystem. To be resolved at the next team meeting.

1. **What device does the operator use at demo time**: laptop or phone? Affects screen sizing and whether keyboard controls are realistic.
2. **Auto-scan or manual scan?** Should the rover continuously stream sensor data, or only when the operator presses "Scan"? Cheaper firmware + clearer demo if manual; more "wow factor" if continuous.
3. **One rock per session, or a list?** Does the UI need to remember the rocks classified so far?
4. **Single git repo or separate repos** for firmware and UI? Single repo is easier; separate is cleaner.
5. **Who owns the `localStorage` history feature?** Nice-to-have, but if no one owns it, it won't ship.

---

## 8. My actions this week (2026-05-13 → 2026-05-20)

- [ ] Walk this doc through the embedded lead in person. Lock §3 (the API contract).
- [ ] Get the starter code flashed and reachable on my own laptop. I have to be able to flash a Metro before I can claim my subsystem works.
- [ ] Scaffold `UI/` under this folder: `index.html`, `app.js`, `styles.css`, `mock_server.py`.
- [ ] Write the mock server first (Python, ~30 lines, returns the §3 JSON shapes).
- [ ] Build the driving panel + WASD keys against the mock server.
- [ ] Bring the mocked, working UI to the team meeting so people can see the contract running, not just read it.

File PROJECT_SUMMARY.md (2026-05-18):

# EEELunarRover Project Summary & Objectives

**Module:** ELEC40006 Electronics Design Project (Year 1 EEE/EIE)
**Team size:** 6 members
**Source materials:** `~/Downloads/EEELunarRover2526-main/`

---

## 1. Project Summary

Design, build, and demonstrate a **remotely-controlled lunar rover (EEELunarRover)** that surveys an artificial lunar surface and classifies rocks placed on it. The rover must work in a lab arena alongside other teams' rovers and compete head-to-head on classification speed.

Each rock is characterised by a combination of four signals: a **radio-transmitted age**, **infrared pulse rate**, **ultrasound presence**, and **static magnetic field direction**. The rover identifies the age and resolves one of four rock types from those measurements.

The build is constrained by a **£60 component budget**, a **750g rover weight limit** (for the arena's weight-sensitive zone), and a **3.3V logic level** on the Adafruit Metro M0 microcontroller.

---

## 2. Rock Characterisation Targets

### 2.1 Age (Radio)

- Carrier: **89 kHz**, two-level **amplitude-shift keying** (ASK, on/off).
- Encoding: **UART, 600 baud, 1 start bit, 1 stop bit, 8 data bits, LSB first**.
- Format: **4 ASCII characters** starting with `#` (e.g. `#123` → 1.23 billion years).

### 2.2 Type (Infrared + Ultrasound + Magnetic)

| Type | IR pulse rate (Poisson) | Ultrasound 40 kHz | Magnet |
|---|---|---|---|
| Basaltoid | λ = 547 s⁻¹ | Present | Down |
| Gravion | λ = 312 s⁻¹ | Absent | Down |
| Regolix | λ = 312 s⁻¹ | Present | Up |
| Lunarite  | λ = 547 s⁻¹ | Absent | Up |

IR pulse width is **50 µs**. Expect small deviations in λ.

### 2.3 Magnetism

Static field, so a stationary coil will not detect it. Need a Hall sensor (or equivalent) capable of resolving **field direction** (up vs. down). Magnets are placed inside each rock during the demo.

---

## 3. Objectives

### 3.1 Functional Objectives

1. **Drive** the rover via a remote interface (WiFi web UI from the starter code as the baseline).
2. **Detect and decode** the 89 kHz ASK/UART radio signal into the 4-character age string.
3. **Measure IR pulse rate** accurately enough to distinguish λ = 312 vs. λ = 547 s⁻¹.
4. **Detect** the 40 kHz ultrasound signal (present/absent).
5. **Detect magnetic field direction** (up vs. down).
6. **Classify each rock** by combining IR + ultrasound + magnet readings, and report age + type back to the operator.
7. **Navigate the arena** reliably between rocks spaced ≥ 500 mm apart, without crossing into uncrossable obstacles.

### 3.2 Non-Functional Objectives

- **Mass:** total rover ≤ 750 g (mandatory for the weight-sensitive zone).
- **Budget:** total component spend ≤ £60.
- **Robustness:** survives repeated demo runs without re-soldering or re-flashing.
- **Usable UI:** operator can drive, take readings, and read classifications without retraining between rocks.
- **3.3 V logic discipline:** every signal entering the Metro M0 is clamped or divided to 0–3.3 V.

### 3.3 Assessment-Driven Objectives

- **Interim presentation (28 May 2026):** high-level design, evidence of progress on each subsystem, plan for remaining work.
- **Final report (11 Jun 2026, 10,000 words):** logical design progression, quantitative justifications, test results, individual contributions.
- **Professional Reflection Forms (11 Jun 2026):** must-pass; cover EDI, teamwork, lifelong learning.
- **Demo (16 Jun 2026):** integrated demonstration on lab bench + competitive arena run.

---

## 4. System Architecture (Initial Cut)

Subsystems to deliver and integrate:

1. **Power**: 5 V from EEEBug batteries; 3.3 V from Metro on-board regulator; clean rails to analogue front-ends.
2. **Drivetrain**: 2× DC motors driven by the supplied H-bridge module (DIR + PWM per channel) on the EEEBug chassis.
3. **Radio front-end**: tuned LC antenna at 89 kHz → amplifier → envelope detector (precision rectifier) → comparator → Metro UART RX (pin 0).
4. **IR front-end**: 950 nm-sensitive photodiode/transistor → trans-impedance amp → high-pass filter to reject 50/100 Hz mains → pulse-counting input.
5. **Ultrasound front-end**: 40 kHz transducer → narrow-band amp/filter → envelope or rectified DC level → comparator.
6. **Magnetic sensor**: Hall-effect sensor capable of distinguishing field polarity.
7. **Controller**: Adafruit Metro M0 Express + WINC1500 WiFi shield, running Arduino framework.
8. **Operator UI**: browser-based UI served by the Metro over WiFi (extends the supplied starter sketch).

Reserved pins on the Metro: **5 (CS), 7 (IRQ), 10 (RST)**: used by the WiFi shield, do not reuse. UART on pin 0 is independent of the USB serial, so radio bytes can be decoded while debug printing continues over USB.

---

## 5. Constraints & Risks

- **Voltage limit:** any input > 3.3 V damages the Metro. Potential dividers + measurement before connection are mandatory.
- **Weight budget:** chassis + electronics + battery must stay under 750 g; track weight every time a component is added.
- **Stock & lead time:** stores orders can take a week; out-of-stock items can take months. Order early, verify stock, avoid surface-mount where possible.
- **Mains interference:** strong 100 Hz harmonic in lab lighting can swamp the IR detector. Filter and/or use 950 nm optical filtering.
- **Diode drop in radio rectifier:** signal may be too small for a plain diode; budget for a precision rectifier with a high-slew opamp.
- **Static magnet detection:** stationary coil won't work; need an actual magnetic sensor selected to detect polarity.
- **Schedule:** with the interim only ~2 weeks away (today is 2026-05-13), at least one end-to-end "any reading at all" path per subsystem is the realistic interim target.

---

## 6. Deliverables Checklist

- [ ] Requirements document (subsystem-level, quantitative)
- [ ] System block diagram with interfaces defined
- [ ] Working drivetrain + remote driving via WiFi UI
- [ ] Radio receive chain decoding `#NNN` strings from the rock simulator
- [ ] IR pulse-rate measurement with discrimination between 312/547 s⁻¹
- [ ] 40 kHz ultrasound presence/absence detection
- [ ] Magnet up/down detection
- [ ] Integrated classification logic on the rover, reporting via the web UI
- [ ] Chassis revision (if needed) within mass and budget limits
- [ ] Test data for every subsystem (for the report's evaluation section)
- [ ] Interim presentation slides (28 May 2026)
- [ ] Final report ≤ 10,000 words (11 Jun 2026)
- [ ] Individual Professional Reflection Forms (11 Jun 2026)
- [ ] Demo build ready (16 Jun 2026)

---

## 7. Reference Materials

All source documents are in `~/Downloads/EEELunarRover2526-main/`:

- `doc/brief.md` - full project brief
- `doc/README.md` - technical guide (hardware kit, hints per subsystem, opamp guidance)
- `doc/deliverables-and-mark-scheme.md` - assessment criteria
- `metro-starter-arduino/` and `metro-starter-pio/` - Metro M0 starter sketch with WiFi web server
- `mech/` - EEEBug chassis design files (DXF, SVG, PDF) for laser cutting

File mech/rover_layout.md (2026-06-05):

# EEELunarRover — mechanical layout & sensor placement

Master mechanical design for mounting the four sensor subsystems, the battery,
the controller and the analogue perfboards onto the existing **EEEBug V3.1**
chassis. The printable parts that implement this are in
[`print/`](print/README.md); the parts to order are in
[`../hardware/BOM.md`](../hardware/BOM.md).

> **See it in 3D:** `print/rover_assembly.scad` combines all the printed parts
> with representative blocks for the chassis, wheels, battery and Metro. Open it
> in OpenSCAD (F5) or look at `print/preview/rover_assembly*.png`.

**Constraints driving every decision:** ≤ **750 g** total, ≤ **£60** budget
(~£55 left), **3.3 V** logic, four analogue front-ends that must not pick up
motor/PWM/mains noise, and a **20 × 20 × 20 cm PLA printer** that we are told
*not* to use to its full extent.

---

## 1. The problem in one line

Place a radio coil, an IR detector, a 40 kHz ultrasonic receiver and a Hall
sensor so they all read a rock on the floor, while keeping the heavy battery
over the drive axle for balance and keeping every weak analogue signal away
from the motors — without breaching 750 g or £55.

---

## 2. Chassis facts (measured from `chassis.svg`)

| Property | Value | Source |
|---|---|---|
| Overall size | **95.0 mm (X) × 205.0 mm (Y)** | SVG bounding box ÷ 96 dpi |
| Material | 3 mm acrylic | `CHASSIS_CAD.md` |
| Drive axle / wheel line | **y ≈ 105 mm (centre)** | width pinches 95→85 mm at y 96–114 (wheel wells) |
| Motor-driver PCB | central, **y ≈ 81–139** | Ø2.6 mm holes on the centreline at y 81.3 & 138.7 |
| Front slots (keep clear) | two 29.6 × 13 mm at y ≈ 3.5 | SVG |
| Mounting holes | M3 (Ø3.1) | SVG (Ø5.86 px) |

**Central M3 anchor holes** (chassis coordinates, the ones we bolt to):

| Row | Left (x) | Right (x) | X-pitch | Used for |
|---|---|---|---|---|
| y = 85  | 10.0 | 85.0 | 75 mm | battery tray (front) |
| y = 95  | 10.5 | 84.5 | 74 mm | **sensor boom** |
| y = 129 | 10.5 | 84.5 | 74 mm | battery tray (rear) |

> **Why a centre axle changes the layout:** the brief says the motor-driver PCB
> is *central* and the Metro mounts at the *rear*; the wheel wells confirm the
> axle is at the middle (y ≈ 105). So the rover **pivots about its centre**.
> Keep the centre of gravity over the axle (both end-skids then carry equal,
> light loads) and put the sensitive sensors on the end **farthest from the
> motor magnets** — the front.

---

## 3. Coordinate system

- **X** = 0…95 mm, left→right across the chassis.
- **Y** = 0 mm at the **front (leading) edge**, 205 mm at the **rear (Metro) edge**.
- The rover drives **front-first** toward the rocks. (Differential drive: which
  way is "forward" is just firmware sign — see `rover_firmware`.)

---

## 4. Top view

```
                      FRONT  (leading edge, y = 0)
        x=0                                            x=95
         +--------------------------------------------+  y=0
         |  [ slot ]                        [ slot ]   |   existing front slots
         |                                            |
         |        .------ SENSOR BOOM ------.         |   boom cantilevers
         |        |  IR | US | HALL (tip)   |>>>>     |   FORWARD past y=0,
         |        |  (down-facing, in line) |         |   skid at the tip
         |   ####################################     |
         |   #   ANTENNA COIL  (Ø50, low)      #      |   y≈20-60, short stand-offs
         |   ####################################     |
         |                                            |
         |  o (10.5, 85)                  (85.0, 85) o |   <- tray anchors
         |  O (10.5, 95)  boom anchors    (84.5, 95) O |   <- BOOM anchors
         | ====================  DRIVE AXLE  ======== |   y=105  wheels L & R
         |        [   MOTOR-DRIVER PCB  (central)  ]  |   y=81-139
         |  o (10.5,129)                 (84.5,129) o |   <- tray anchors
         |   +======= 4xAA BATTERY on tray =======+   |   raised OVER the axle
         |   |     (heaviest item, over y=105)    |   |
         |   +====================================+   |
         |                                            |
         |        [  METRO M0  +  WiFi shield  ]      |   y≈150-205 (rear mount)
         |                                            |
         +--------------------------------------------+  y=205
                      REAR  (Metro end)

   O = boom standoff   o = battery-tray standoff
```

The three sensor housings sit **in a line on the centre line at the boom tip**,
all facing **down** at the rock the rover noses up to. The big radio coil sits
low and flat just behind them. The battery is the only heavy item and it sits
**directly over the axle**.

## 5. Side view (heights, not to scale)

```
        battery tray  ____________________
                      |  4xAA on tray     |  ~25 mm standoffs (clears PCB)
   motor-driver PCB ..|...................|..
         deck  _______|___________________|________  Metro+WiFi
   ____________|__________ chassis (3mm acrylic) ___________
   boom  ____ /                                    \____ skids
        /  IR US HALL  <- low, near floor             wheels Ø~65
   ====O========================(o)=====================O====  FLOOR
        ^ front skid (=Hall pod)   ^ drive wheel
```

The boom drops the sensors **low and forward** (small air-gap to the rock); the
battery rises **high and central** (over the axle). The Hall pod at the boom tip
is the lowest point and **doubles as the front skid**.

---

## 6. Where each subsystem goes, and why

### 6.1 Radio / age (89 kHz coil)
- **Where:** front-**left**, low and flat (coil axis vertical), on the Ø36
  low-profile bobbin, ~20–60 mm from the front edge. Off the boom centre-line so
  the boom can sit low (see the assembly model). Its demodulator perfboard
  mounts right next to it (short antenna leads).
- **Why:** the rock radiates from a coil in the plane of its PCB on the floor,
  so a horizontal pickup coil held low and close couples best. The signal is
  tiny and needs a precision rectifier, so the antenna→amp wire must be short
  and **far from the motors (PWM brush noise) and the battery/DC rail**. Front
  is ~105 mm from the central motors. Decoded UART goes to **Metro D0**.

### 6.2 Infrared / type (SFH 300)
- **Where:** boom tip, down-facing, inside the **IR shroud** (light-tight tube).
- **Why:** the rock's 50 µs IR pulses are weak and easily swamped by the lab's
  100 Hz lighting harmonic. The shroud blocks side/ambient light; the existing
  trans-impedance + high-pass + comparator chain (`../hardware/ir_sensor_build.md`)
  rejects the rest. Keep the SFH 300 leads short to its amp → its perfboard
  rides on the boom. Comparator output → **Metro D2** (edge counting).

### 6.3 Ultrasound / type (Murata MA40S4R)
- **Where:** boom tip, down-facing, in the **ultrasound clamp**, next to the IR.
- **Why:** presence/absence of 40 kHz only — point the receiver at the rock and
  band-pass + rectify. Robust digital "present/absent" output, so its routing is
  not noise-critical. → an unused Metro pin (assign in `pin_map.md`).

### 6.4 Magnetic / type (Honeywell SS49E)
- **Where:** the **lowest** point of the boom tip (Hall pod), front-most, facing
  down. **This is the placement that matters most.**
- **Why:** two competing pulls — it must get *close* to the magnet inside the
  rock (field falls as ~1/distance³; aim for a ≥ 5 mT air-gap, i.e. as low as
  possible) **and** stay *far* from the rover's own DC-motor magnets, which
  would bias the reading. Centre-axle motors sit ~105–125 mm behind the pod —
  far enough. Ratiometric output (≈ V/2 at zero field, above for one polarity,
  below for the other) → a Metro analogue input; **up vs down = above/below
  mid-rail.** Take a *motors-off* baseline in firmware and threshold around it.

### 6.5 Battery (4 × AA)
- **Where:** on the printed tray, raised over the axle (y 85–129), above the
  central motor-driver PCB.
- **Why:** heaviest single item (~100 g). Over the axle it balances the
  centre-pivot rover and loads the drive wheels for traction, while its
  switching noise stays well away from the front analogue front-ends.
  **Do not order cells** — they are in the kit and batteries are a forbidden
  order line.

### 6.6 Controller (Metro M0 + WiFi shield)
- **Where:** rear (y 150–205), on the chassis's existing rear Metro mount.
- **Why:** keeps the WiFi shield and its digital switching away from the front
  analogue section, and balances some weight behind the axle against the
  forward boom. Pins 5/7/10 reserved for WiFi (do not reuse).

---

## 7. Mounting-hole assignment

| Printed part | Bolts to chassis holes | Fastener |
|---|---|---|
| Sensor boom | (10.5, 95) & (84.5, 95) | 2× M3 nylon standoff, short (sensors low) |
| Battery tray | (10.0, 85) & (85.0, 85) & (10.5, 129) & (84.5, 129) | 4× M3 nylon standoff, ~25 mm (clear the PCB) |
| Antenna bobbin | front holes / zip-tie through chassis | 2× M3 or cable tie |
| Perfboard carriers | onto boom or central deck (2× M3 @ 12 mm) | M3 nylon |
| Sensor housings | onto the boom docks (2× M3 @ 12 / 20 mm) | M3 nylon |

The boom (y = 95) and tray (y = 85/129) never share a hole. The ≤ 1 mm pitch
difference between the y = 85 row (75 mm) and the y = 95/129 rows (74 mm) is
absorbed by Ø3.4–3.6 mm clearance holes. **Verify all holes on the physical
board** — laser kerf widens internal holes ~0.1–0.2 mm.

---

## 8. Verified part dimensions (used in the 3D models)

| Part | Used for | Dimensions driving the model | Source |
|---|---|---|---|
| OSRAM **SFH 300** | IR shroud bore | 5 mm T-1¾ radial, body **Ø5.1 mm**, ~8.6 mm tall, 2.54 mm leads | ams-OSRAM datasheet |
| Murata **MA40S4R** | ultrasound clamp bore | body **Ø9.9 mm**, **7.1 mm** tall, **5.0 mm** lead pitch | Murata DM-U16-483 |
| Honeywell **SS49E** | Hall pod slot | flat pkg **4.1 × 1.7 × 3.0 mm**, 1.27 mm leads, 2.7–6.5 V | Honeywell datasheet |
| Microchip **MCP6292-E/P** | on perfboards | **PDIP-8** (through-hole), RRIO, 10 MHz/7 V/µs | Microchip DS20001812G |
| Roth **RE015 / RE016** | perfboard carriers | **40.5 × 40** / **68.58 × 67.94 × 1.5 mm** | RS product pages |
| M3 nylon hex | print clearances | across-flats **5.4–5.6 mm** | Rapid R-TECH pages |

> **Flags carried from research:** the SFH 300 *height* (~8.6 mm) was not crisp
> on the datasheet drawing — callipers before finalising the shroud length. The
> SS49E reads polarity but at ~14 mV/mT; if the air-gap to the rock magnet is
> large, switch to the **SS495A** (31 mV/mT) — same body, but it needs the 5 V
> rail, not 3.3 V.

---

## 9. Weight budget (target ≤ 750 g)

| Item | Est. mass (g) | Notes |
|---|---|---|
| Acrylic chassis | 60 | 95 × 205 × 3 mm, less cut-outs |
| 2× gear motors | 60 | existing |
| 2× wheels + tyres | 60 | existing |
| End skids / caster | 10 | existing + printed Hall-pod skid |
| 4× AA + holder | 107 | **kit** (do not order) |
| Metro M0 + WiFi shield | 40 | existing |
| Motor-driver module | 10 | kit |
| Wiring / headers / connectors | 35 | |
| 3× populated sensor perfboards | 36 | IR, radio, ultrasound front-ends |
| Sensor elements (SFH300, MA40S4R, SS49E) | 5 | |
| Antenna coil (enamelled wire) | 15 | hand-wound |
| **3D-printed PLA mounts** (boom, 4 housings, tray, 3 carriers) | **~50** | 25 % infill — see below |
| Nylon fasteners / standoffs | 15 | |
| **Total** | **≈ 503 g** | **~247 g margin** |

Comfortable margin, **but track it on a kitchen scale every time a part is
added** — the estimate has ±15 % in it. The printed PLA total is the easiest
lever: 25 % infill and the lightening holes already modelled keep it near 50 g.

---

## 10. Keep-out / interference zones

- **Motor magnet zone** (centre, under the chassis): keep the **Hall sensor**
  out of it — hence the front boom tip. Re-check by reading the Hall with motors
  running and no rock: it must stay near mid-rail.
- **Wheel sweep** (sides at y 96–114): nothing may protrude into the wheel wells
  below deck height.
- **PWM / brush noise** (motors + driver PCB, centre): route the radio and IR
  analogue lines away from it; do their analogue processing on the boom and send
  only clean digital/low-impedance signals back.
- **WiFi shield** (rear): the 89 kHz coil won't disturb 2.4 GHz, but keep the
  coil and its high-gain amp physically away from the digital boards anyway.

---

## 11. Assembly order

1. Bolt the **antenna bobbin** low at the front-centre; wind & tune the coil
   (LCR bridge) before anything blocks access.
2. Bolt the **sensor boom** to the y = 95 holes on short standoffs.
3. Clip the **IR shroud**, **ultrasound clamp** and **Hall pod** onto the boom
   docks; the Hall pod sets the front skid height (lowest point).
4. Mount each sensor's **perfboard carrier** (boom or central deck), keeping
   weak-signal leads short.
5. Fit the **battery tray** on ~25 mm standoffs at y = 85 / 129, over the axle;
   zip-tie the AA holder in.
6. Confirm the **Metro + WiFi** at the rear is undisturbed; run wiring looms
   down the sides (chassis cable slots), not across the motors.
7. Weigh the rover. Read every sensor with motors **off**, then **on**, and
   confirm none of them drifts past its decision threshold.

---

## 12. To verify on the physical rover (do not skip)

- [ ] Drive axle really is central (wheel wells at y ≈ 105) — if the motors are
  actually at one end, **swap the boom and Metro ends** (the principle holds:
  sensors farthest from motors).
- [ ] Exact battery-holder footprint → set `bat=[L,W]` in `battery_tray.scad`.
- [ ] SFH 300 body height → IR shroud tube length.
- [ ] Hall air-gap vs SS49E sensitivity → SS49E (3.3 V) or SS495A (5 V).
- [ ] All M3 holes accept M3 after kerf.
- [x] **Boom vs antenna clearance** (found and fixed in the 3D assembly): the
  antenna was moved front-LEFT off the boom centre-line and shrunk to a low
  Ø36 × 11 mm former, so the boom now sits low (~12 mm) and the Hall pod (now
  ~30 mm, parametric) reaches near the floor. Confirm the real air-gap on the
  bench and tune `postH` / boom standoff length.

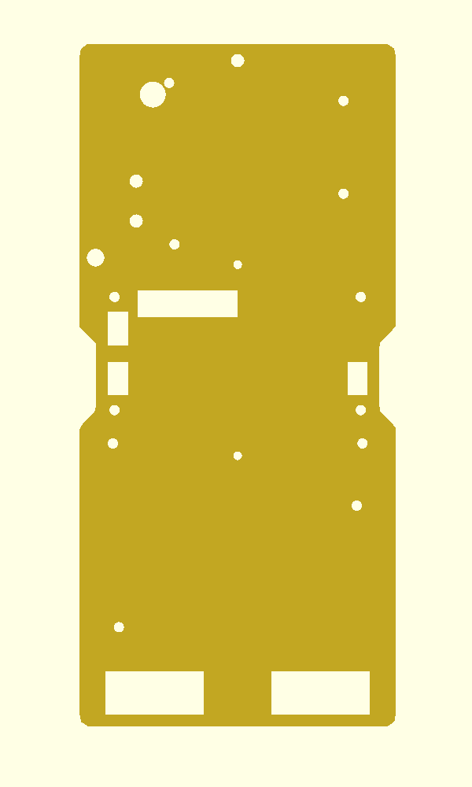
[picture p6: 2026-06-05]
mech/print/preview/chassis.png

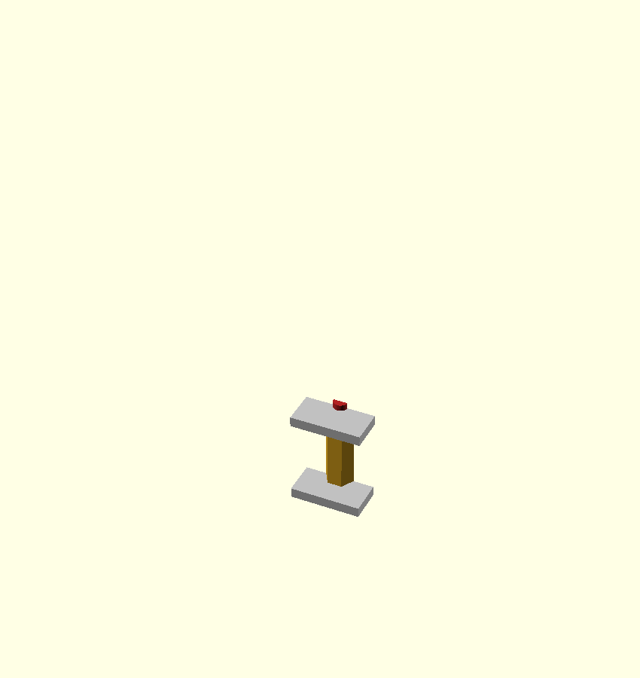
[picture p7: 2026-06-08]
mech/stacked_deck/preview/joint_section.png

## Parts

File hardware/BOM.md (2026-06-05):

# Bill of materials — EEELunarRover sensor build

Parts to order for the sensor subsystems and the printed-mount hardware, mapped
to the **allowed EEE Stores suppliers** (RS, OneCall/Farnell, CPC, Rapid).
Ordering goes through one nominated approver on the
[EEE Stores order form](https://www.imperial.ac.uk/electrical-engineering/internal/stores/).

> **Prices are estimates.** Every RS/Farnell/CPC/Rapid product page blocks
> automated price scraping, so the figures below are indicative — **the approver
> must read the live price on the order form before submitting.** Order codes
> and dimensions are datasheet/catalogue-verified.

## Ordering rules honoured (from `doc/README.md`)
- ❌ **No batteries** — the 4×AA cells are in the kit; batteries are a forbidden order line.
- ❌ **No glue / chemicals** — parts are retained by **screws and zip-ties**, not adhesive.
- ❌ **No tools / mains equipment.**
- ✅ **Through-hole only** — every active part below is leaded/DIP, no surface-mount.
- ✅ **Check stock** before ordering (avoid months-long back-orders).
- The **magnet** is in the kit. The **Metro, WiFi shield, motor driver, breadboard** are in the kit.

---

## Group A — specialist parts (order from RS / Farnell / CPC / Rapid)

These are the budget-critical sensor parts. Buy a spare of the small/cheap ones.

| # | Part | For | Supplier | Order code | Qty | Unit (est) | Line (est) | Key dims |
|---|---|---|---|---|---|---|---|---|
| 1 | Murata **MA40S4R** 40 kHz Rx | ultrasound | CPC (or Farnell 1777668) | **SN36522** | 2 | £2.50 | £5.00 | Ø9.9 × 7.1 mm, 5.0 mm leads |
| 2 | Honeywell **SS49E** Hall | magnetic | RS (or Farnell 1225624) | **236-2760** | 2 | £1.50 | £3.00 | 4.1 × 1.7 × 3.0 mm, 2.7–6.5 V |
| 3 | OSRAM **SFH 300** phototransistor | infrared | Farnell (or RS 654-8031) | **2981724** | 2 | £0.60 | £1.20 | 5 mm T-1¾, Ø5.1 mm |
| 4 | Microchip **MCP6292-E/P** dual op-amp | IR/radio/US front-ends | Farnell | **1439466** | 3 | £1.00 | £3.00 | **PDIP-8**, RRIO, 10 MHz/7 V/µs |
| 5 | Roth **RE016-LF** perfboard | large sensor board (cut in 2) | RS | **897-1402** | 1 | £3.39 | £3.39 | 68.58 × 67.94 × 1.5 mm |
| 6 | Roth **RE015-LF** perfboard | small sensor boards | RS | **897-1408** | 2 | £1.63 | £3.26 | 40.5 × 40 × 1.5 mm |
| | | | | | | **Subtotal A** | **≈ £18.85** | |

Notes:
- **MCP6292 in DIP is real** — the through-hole part is the **-E/P** suffix
  (the SOIC/MSOP variants are -E/SN, -E/MS; do **not** order those). The team's
  "8-pin DIP" assumption is correct. One part covers the 547 Hz IR stage and the
  89 kHz radio precision-rectifier/comparator stage (10 MHz, 7 V/µs).
- **Hall choice:** SS49E runs natively at 3.3 V (~14 mV/mT). If the air-gap to
  the rock magnet turns out large, switch to **SS495A** (RS 216-6231, ~31 mV/mT)
  — same body, but it needs the **5 V** rail.
- Ultrasound is presence-only, so a **receiver alone** is enough (no Tx). If you
  later want an active ping, add MA40S4S (CPC SN36521).
- Four sensor circuits need 4 board areas: one RE016 cut in half + two RE015 = 4.

## Group B — commodity parts (try EED Stores dept stock FIRST, then order)

Fasteners, passives, headers and magnet wire are usually held as **EED Stores
department stock** (collect same-day, little/no budget hit). Only place a
supplier order for whatever the department doesn't stock.

| # | Part | For | Supplier | Order code | Qty | Unit (est) | Line (est) |
|---|---|---|---|---|---|---|---|
| 7 | M3 nylon hex standoff, M-F, 15 mm (pk 100) | mount boom/tray (light) | Rapid | **52-4352** | 1 | £7.63 | £7.63 |
| 8 | M3 steel pan screw, 6 mm (pk 100) | board & module screws | Rapid | **33-7089** | 1 | £4.59 | £4.59 |
| 9 | M3 steel hex nut (pk 100) | lock standoffs to chassis | Rapid | **33-7173** | 1 | £3.89 | £3.89 |
| 10 | Enamelled copper wire 0.28 mm, solderable | 89 kHz antenna coil | RS | **779-0700** | 1 | £8–12 | £10.00 |
| 11 | 0.1″ pin headers + M-M jumper leads | inter-board wiring | CPC / dept stock | — | — | £3.00 | £3.00 |
| 12 | Resistors + capacitors (IR/radio/US front-ends) | front-ends | dept stock / lab kit | — | — | £3.00 | £3.00 |
| | | | | | | **Subtotal B** | **≈ £32.11** |

Notes:
- **Magnet wire** (item 10) is the biggest single line — check EED Stores dept
  stock first; 0.28 mm enamelled wire is a common stock item and would free ~£10.
- Nylon standoffs save weight vs steel (750 g limit). Confirmed M3 nylon hex
  across-flats = **5.4–5.6 mm** (the printed parts clear 5.8 mm). A confirmed
  pan-head **nylon** M3 screw wasn't found at an allowed supplier — steel M3×6
  (item 8) is the safe choice; the few grams are negligible.
- Zip-ties retain the battery holder and Hall sensor (no glue). Add a small pack
  if not in dept stock.

---

## Budget summary

| Scenario | Spend | vs £55 |
|---|---|---|
| Everything ordered from suppliers (A + B) | **≈ £51** | under, ~£4 headroom |
| Group B mostly from EED Stores dept stock | **≈ £20–25** | comfortable |

**Stay under £55 by drawing fasteners, passives, headers and (ideally) the
magnet wire from EED Stores department stock**, and reserving the supplier
budget for the specialist sensor parts in Group A. Re-confirm every price on the
order form — the figures here are estimates pending the bot-blocked live pages.

## Already in the kit (do **not** order)
4×AA cells · 2× magnet · Metro M0 · WINC1500 WiFi shield · H-bridge motor driver
· breadboard · USB cables · rock simulator.

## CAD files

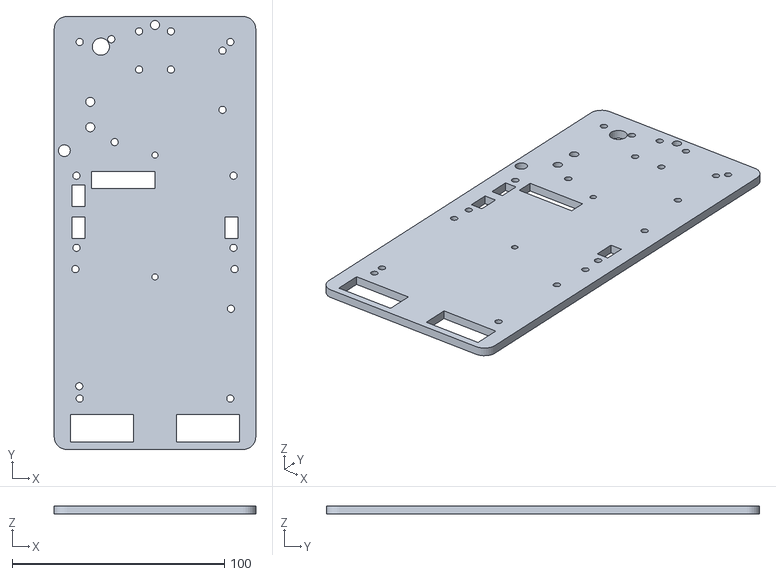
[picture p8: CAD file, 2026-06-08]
mech/stacked_deck/stl/deck_full.stl
95.0 x 204.0 x 4.00

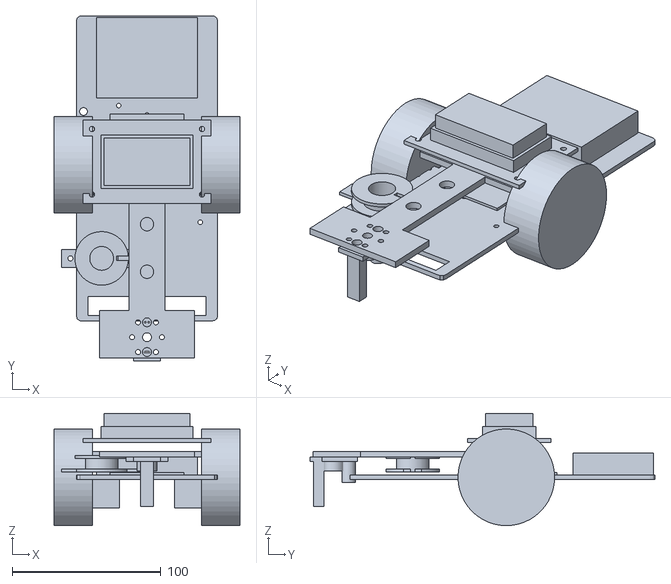
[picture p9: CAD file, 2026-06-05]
mech/print/stl/rover_assembly.stl
125.0 x 232.0 x 75.5

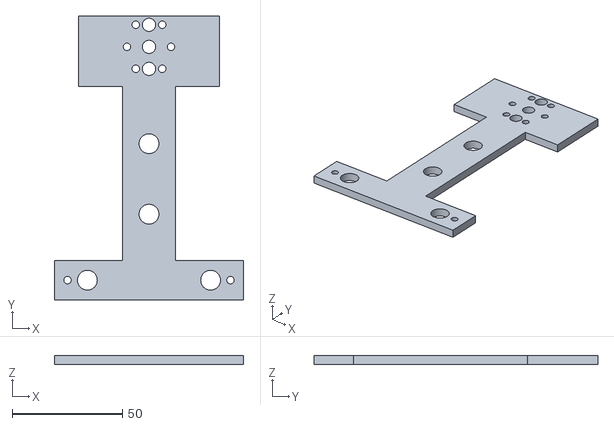
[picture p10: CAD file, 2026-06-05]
mech/print/stl/boom.stl
86.0 x 129.0 x 4.00

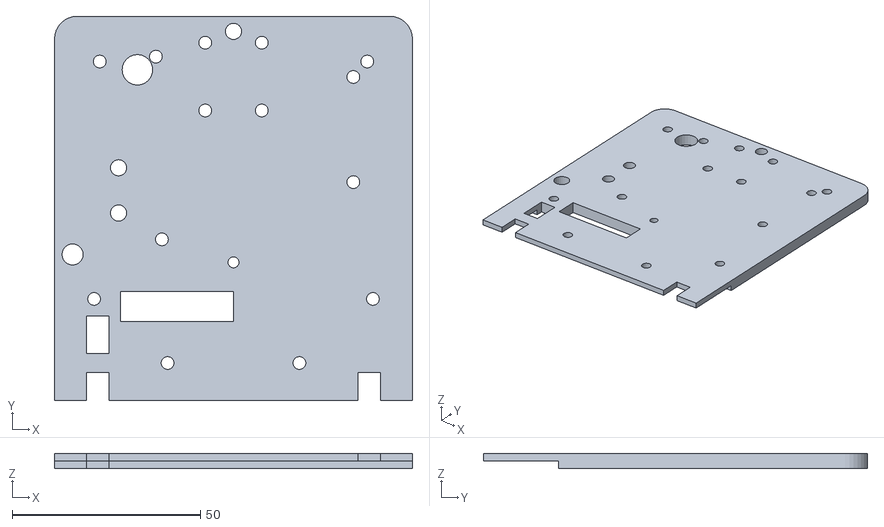
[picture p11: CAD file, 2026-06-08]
mech/stacked_deck/to_print/deck_half_B.stl
95.0 x 102.0 x 4.00

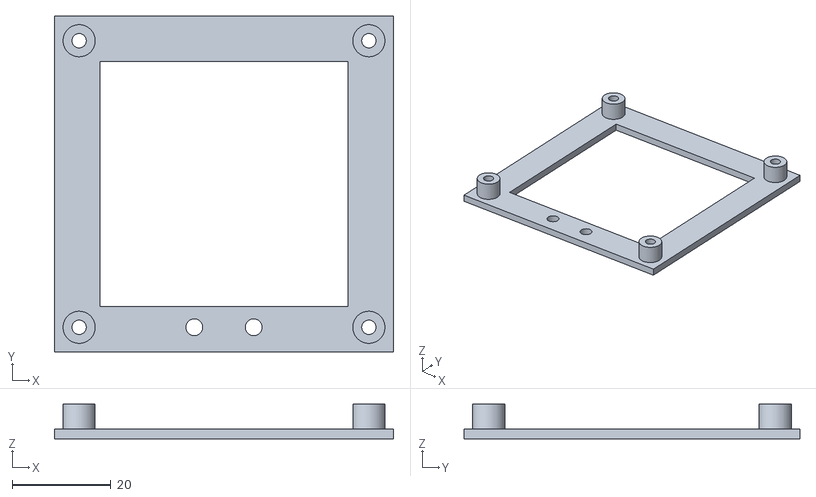
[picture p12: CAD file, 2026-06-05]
mech/print/stl/perfboard_carrier_large.stl
68.6 x 67.9 x 7.00

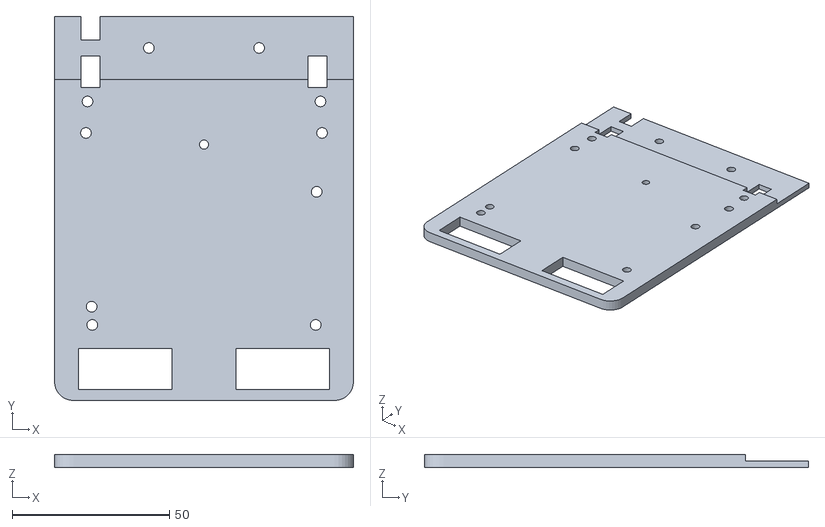
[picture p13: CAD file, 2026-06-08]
mech/stacked_deck/to_print/deck_half_A.stl
95.0 x 122.0 x 4.00

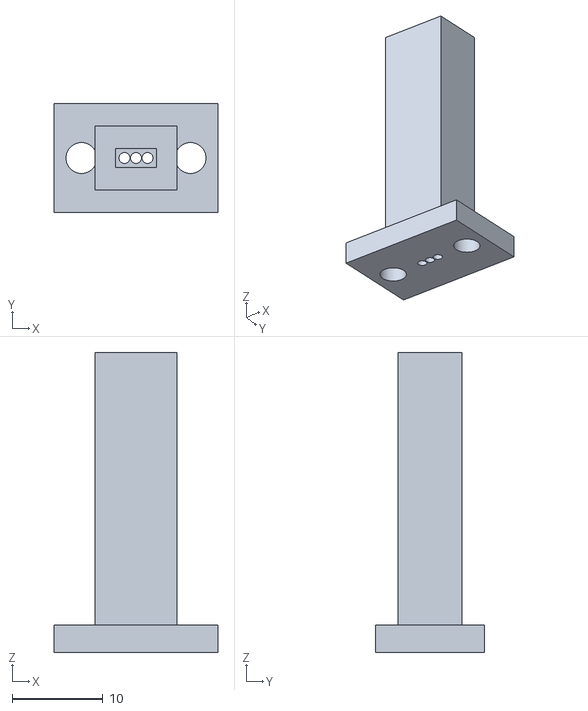
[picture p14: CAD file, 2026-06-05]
mech/print/stl/hall_pod.stl
18.0 x 12.0 x 33.0

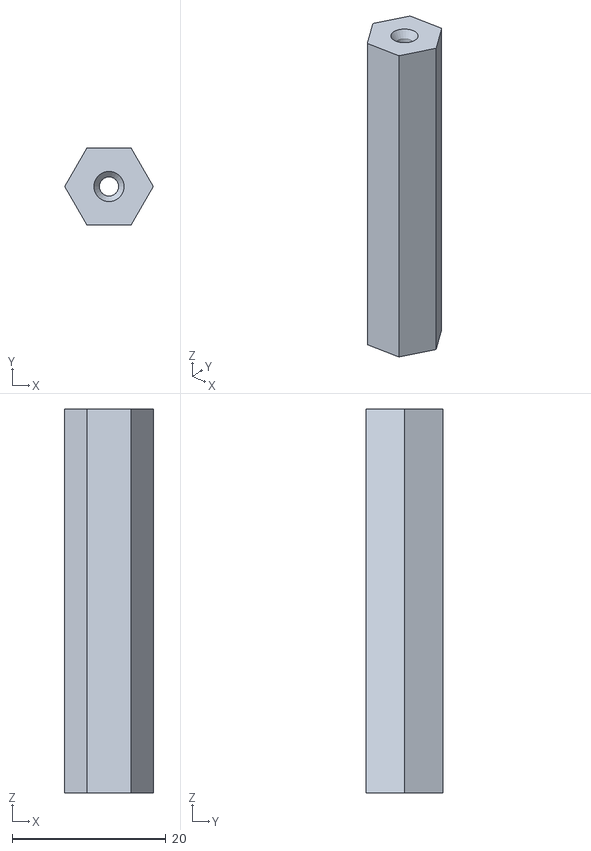
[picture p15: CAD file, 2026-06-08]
mech/stacked_deck/to_print/pillar.stl
11.5 x 10.0 x 50.0

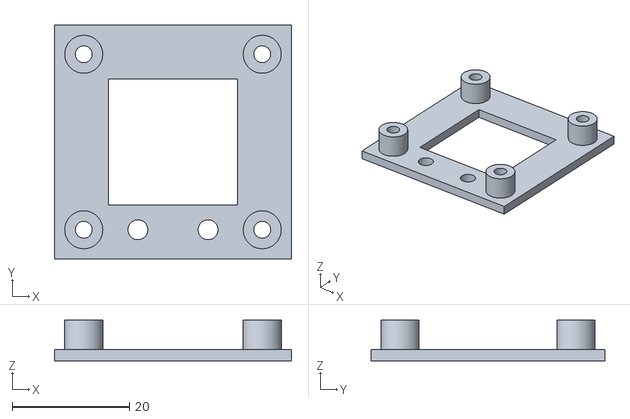
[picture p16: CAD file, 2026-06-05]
mech/print/stl/perfboard_carrier_small.stl
40.5 x 40.0 x 7.00

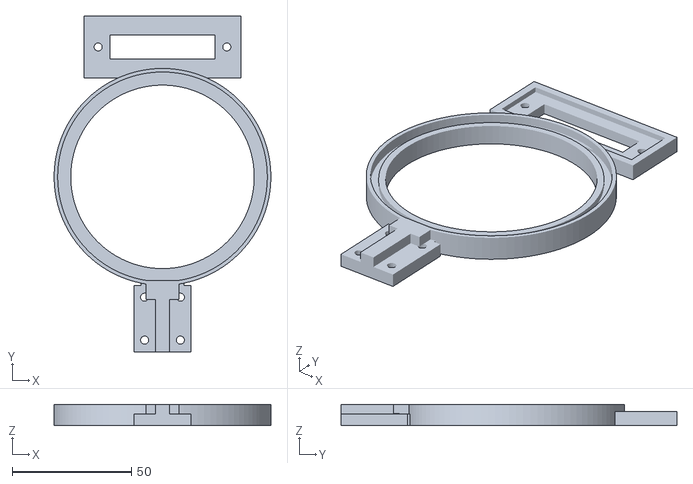
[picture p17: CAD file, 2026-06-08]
mech/stacked_deck/to_print/coil_support.stl
91.0 x 141.0 x 9.00

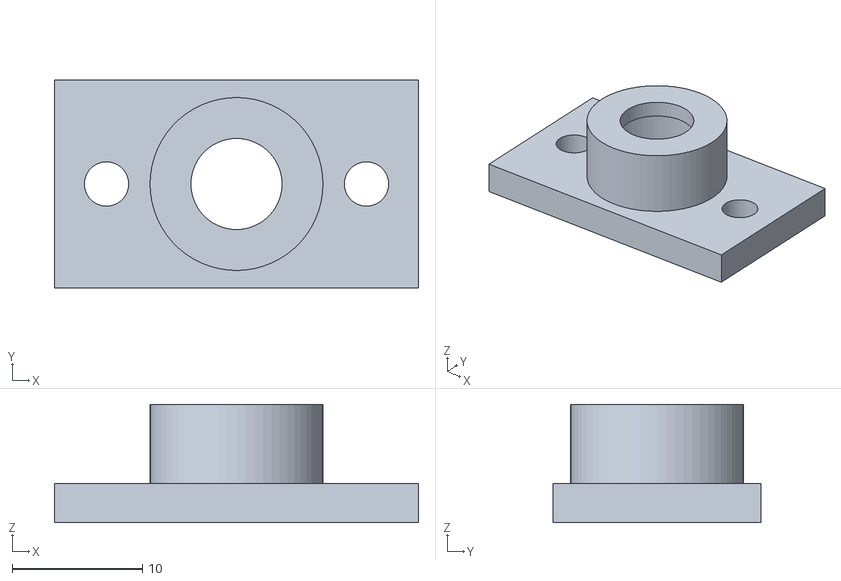
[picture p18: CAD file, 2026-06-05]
mech/print/stl/ultrasound_clamp.stl
28.0 x 16.0 x 9.10

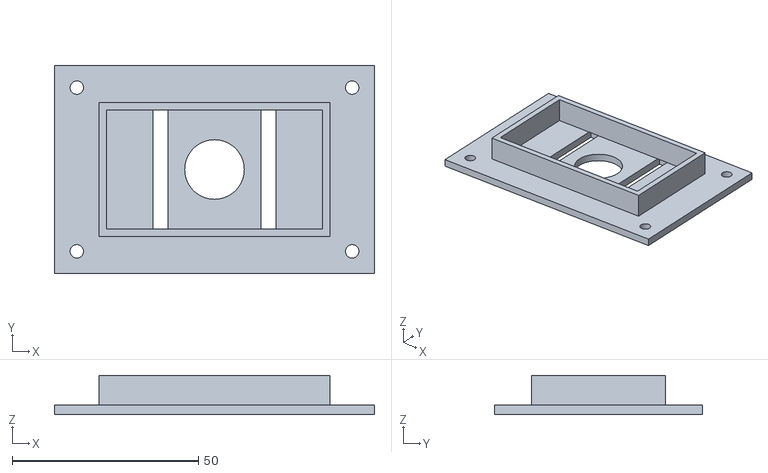
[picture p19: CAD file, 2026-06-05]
mech/print/stl/battery_tray.stl
86.0 x 56.0 x 10.5

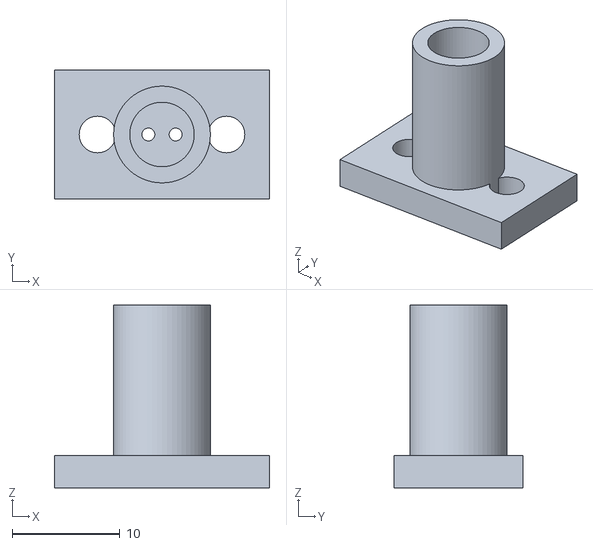
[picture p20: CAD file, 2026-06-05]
mech/print/stl/ir_shroud.stl
20.0 x 12.0 x 17.0

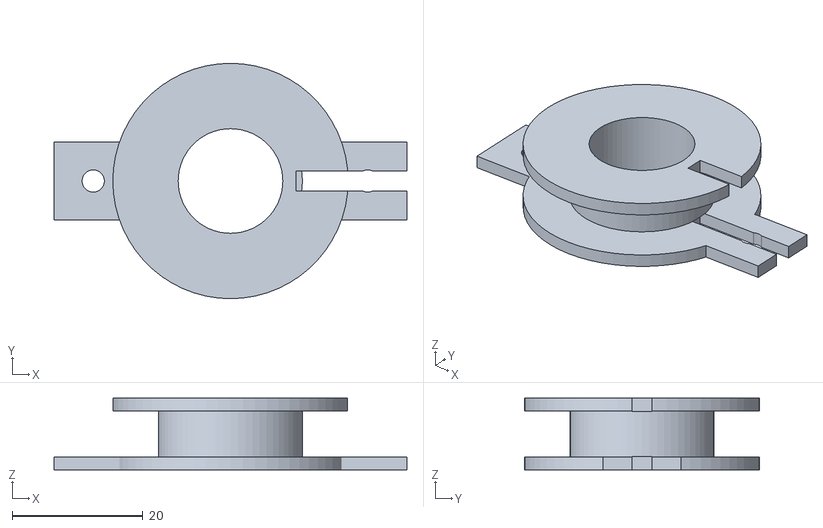
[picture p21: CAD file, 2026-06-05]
mech/print/stl/antenna_bobbin.stl
54.0 x 36.0 x 11.0

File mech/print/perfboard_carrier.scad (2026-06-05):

// ============================================================================
// perfboard_carrier.scad - universal sled for a Roth FR4 perfboard
// ----------------------------------------------------------------------------
// Holds one analogue-front-end perfboard 5 mm above its mount surface (lead /
// solder clearance) and bolts onto the central deck or the boom with 2x M3.
// Default size = Roth RE015 (40.5 x 40 mm); set board=PB_LARGE for RE016.
//
// The board is retained by 4 corner bosses tapped for M3 - drill Ø3.2 holes in
// the perfboard 5 mm in from each corner. A large central window saves weight
// and lets leads/solder protrude.
//
// Print FLAT, no supports. Footprint = board + 5 mm.
//   openscad -o perfboard_carrier_small.stl perfboard_carrier.scad
//   openscad -D 'board=PB_LARGE' -o perfboard_carrier_large.stl perfboard_carrier.scad
// ============================================================================

include <common.scad>

board   = PB_SMALL;   // [L, W, thickness]
BASE_T  = 2;          // sled floor thickness
STAND   = 5;          // board stand-off height (lead clearance)
INSET   = 5;          // boss / drill inset from board corner
BOSS_D  = 6.5;

module perfboard_carrier() {
    L = board[0]; W = board[1];
    fx = L/2 - INSET; fy = W/2 - INSET;
    difference() {
        union() {
            // floor
            translate([-L/2, -W/2, 0]) cube([L, W, BASE_T]);
            // corner bosses
            for (sx = [-1,1], sy = [-1,1])
                translate([sx*fx, sy*fy, 0]) cylinder(d = BOSS_D, h = BASE_T + STAND);
        }
        // lightening window
        translate([0,0,-eps])
            translate([-(L/2-INSET-BOSS_D/2-1), -(W/2-INSET-BOSS_D/2-1), 0])
            cube([2*(L/2-INSET-BOSS_D/2-1), 2*(W/2-INSET-BOSS_D/2-1), BASE_T+2*eps]);
        // M3 tap holes in bosses
        for (sx = [-1,1], sy = [-1,1])
            translate([sx*fx, sy*fy, 0]) m3_tap(BASE_T + STAND);
        // 2x M3 mounting holes through the floor, near one edge, DOCK_PITCH apart
        for (s = [-1,1]) translate([s*DOCK_PITCH/2, -(W/2 - INSET), -eps])
            cylinder(d = M3_CLEAR, h = BASE_T + 2*eps);
    }
}

perfboard_carrier();

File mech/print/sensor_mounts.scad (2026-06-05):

// ============================================================================
// sensor_mounts.scad - the four bolt-on sensor housings for the boom / chassis
// ----------------------------------------------------------------------------
// Each module shares the standard interface: a flat base with 2x M3 clearance
// holes at DOCK_PITCH (12 mm). Render one at a time, e.g.:
//     openscad -D 'part="ir"'      -o ir_shroud.stl       sensor_mounts.scad
//     openscad -D 'part="us"'      -o ultrasound_clamp.stl sensor_mounts.scad
//     openscad -D 'part="hall"'    -o hall_pod.stl         sensor_mounts.scad
//     openscad -D 'part="antenna"' -o antenna_bobbin.stl   sensor_mounts.scad
//
// All print FLAT (base on the bed, feature pointing up); in use the IR/US/Hall
// parts are flipped so the optics/transducer/Hall face DOWN toward the rock.
// ============================================================================

include <common.scad>

part = "all";   // overridden on the command line with -D

// --- 2x M3 mounting holes through a base, centred on origin -------------------
module base_with_bolts(bx, by, bt, pitch = DOCK_PITCH) {
    difference() {
        translate([-bx/2, -by/2, 0]) cube([bx, by, bt]);
        for (s = [-1,1]) translate([s*pitch/2, 0, -eps])
            cylinder(d = M3_CLEAR, h = bt + 2*eps);
    }
}

// --- IR shroud: light-tight tube around the SFH 300 (5 mm T-1 3/4 body) ------
// Bore Ø6.0 clears the ~5.9 mm package RIM (not just the Ø5.1 lens). 1.5 mm
// wall, 14 mm tall to block side/ambient light. Insert the SFH 300 leads-first
// through the two Ø1.2 holes (2.54 mm pitch); the lens then faces out the open
// end. In use, flip so the open (lens) end faces DOWN at the rock.
module ir_shroud() {
    bx = 20; by = 12; bt = 3; tubeH = 14; boreD = 6.0; odD = boreD + 3.0;
    difference() {
        union() {
            base_with_bolts(bx, by, bt);
            cylinder(d = odD, h = bt + tubeH);
        }
        translate([0,0,bt]) cylinder(d = boreD, h = tubeH + 1);          // body bore (open top)
        for (s = [-1,1]) translate([s*1.27, 0, -eps])                    // 2 leads @ 2.54 mm
            cylinder(d = 1.2, h = bt + 2*eps);
    }
}

// --- Ultrasound clamp: holds the Murata MA40S4R (Ø9.9 body, 7.1 tall) --------
// Open-base tube: the transducer inserts FACE-first from the flange (base) end
// until the active face meets the Ø7 retaining lip; the 2 leads exit the open
// base to the perfboard. Bolt pitch 20 mm clears the Ø13.3 tube. In use, flip
// so the lip (face) end points DOWN at the rock.
module ultrasound_clamp() {
    bx = 28; by = 16; ft = 3; PITCH = 20;
    boreD = US_DIA + 0.2; odD = boreD + 3.2; lip = 7.0;
    boreH = US_H + 0.5; lipT = 1.5; totalH = boreH + lipT;   // ~9.1 mm
    difference() {
        union() {
            translate([-bx/2, -by/2, 0]) cube([bx, by, ft]);   // bolt flange (open centre)
            cylinder(d = odD, h = totalH);                      // tube
        }
        translate([0,0,-eps]) cylinder(d = boreD, h = boreH + eps);   // body bore (open base)
        translate([0,0,boreH]) cylinder(d = lip, h = lipT + eps);     // face aperture / lip
        for (s = [-1,1]) translate([s*PITCH/2, 0, -eps])              // bolt holes
            cylinder(d = M3_CLEAR, h = ft + 2*eps);
    }
}

// --- Hall pod: holds the flat SS49E at the boom tip and reaches toward the
// floor (also the front skid). The post length is THE knob that sets the Hall
// air-gap to the rock magnet - lengthen/shorten postH to suit the boom height.
// Slot 4.5 x 2.1 mm captures the flat package at the tip; flying leads run up
// the 3 lead holes (1.27 mm pitch) to the perfboard.
module hall_pod(postH = 30) {
    bx = 18; by = 12; bt = 3; px = 9; py = 7;
    difference() {
        union() {
            base_with_bolts(bx, by, bt);
            translate([0,0,bt]) linear_extrude(postH) square([px, py], center = true);
        }
        // capture slot, open at the far (tip) end
        translate([-(HALL_W+0.4)/2, -(HALL_T+0.4)/2, bt+postH-6])
            cube([HALL_W+0.4, HALL_T+0.4, 6.1]);
        for (i = [-1,0,1]) translate([i*1.27, 0, -eps])    // lead channels
            cylinder(d = 1.2, h = bt + postH);
    }
}

// --- Antenna bobbin: former for the hand-wound 89 kHz tuned coil -------------
// Low-profile Ø36 former (11 mm tall) so it tucks UNDER the boom and sits
// front-LEFT, off the boom centre-line. Air core (Ø16 bore). Wind enamelled
// copper on the Ø22 core, 7 mm wide (build the turns up radially - there's
// 7 mm of room to the flange). Mount via the 2 ears (~42 mm pitch) or zip-tie.
// Tune turns with the lab LCR bridge.
module antenna_bobbin() {
    coreOD = 22; coreID = 16; flangeOD = 36; flangeT = 2; windW = 7; earL = 12; earW = 12;
    earX = flangeOD/2 + earL/2 - 3;   // -> ~42 mm pitch
    difference() {
        union() {
            cylinder(d = flangeOD, h = flangeT);                              // bottom flange
            cylinder(d = coreOD,   h = flangeT + windW);                      // core
            translate([0,0,flangeT+windW]) cylinder(d = flangeOD, h = flangeT); // top flange
            for (s = [-1,1]) translate([s*earX, 0, 0])
                translate([-earL/2, -earW/2, 0]) cube([earL, earW, flangeT]);
        }
        translate([0,0,-eps]) cylinder(d = coreID, h = 2*flangeT + windW + 2*eps); // air bore
        for (s = [-1,1]) translate([s*earX, 0, -eps]) cylinder(d = M3_CLEAR, h = flangeT + 2*eps);
        // wire lead-out notches in both flanges
        for (z = [0, flangeT+windW])
            translate([coreOD/2 - 1, -1.5, z-eps]) cube([flangeOD/2, 3, flangeT + 2*eps]);
    }
}

// --- render selector ---------------------------------------------------------
if      (part == "ir")      ir_shroud();
else if (part == "us")      ultrasound_clamp();
else if (part == "hall")    hall_pod();
else if (part == "antenna") antenna_bobbin();
else {  // "all" - lay them out for a preview
    translate([-30,0,0]) ir_shroud();
    translate([  0,0,0]) ultrasound_clamp();
    translate([ 30,0,0]) hall_pod();
    translate([  0,50,0]) antenna_bobbin();
}

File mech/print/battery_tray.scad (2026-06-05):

// ============================================================================
// battery_tray.scad - 4xAA holder cradle, mounted over the drive axle
// ----------------------------------------------------------------------------
// Bolts to all four central anchor holes (74 x 34 mm rectangle) on M3 nylon
// standoffs, raising the battery pack above the existing Metro / motor-driver
// PCB. Keeping the heaviest item (~100 g of AA cells) directly over the axle
// (y = 105 mm) balances the centre-pivot rover so both end skids stay light.
//
// The AA holder drops into the walled pocket and is held by a zip-tie through
// the two slots (no glue - lab rules forbid ordering adhesives, and a zip-tie
// lets you swap cells). Default pocket fits a 2x2 AA holder; measure yours and
// override bat=[L,W].
//
// Bolts to the chassis y = 85 and y = 129 hole pairs (the boom takes y = 95).
// Their midpoint y = 107 sits over the drive axle (105). Holes are Ø3.6 to
// absorb the ~1 mm pitch / 0.5 mm x variation between those two hole rows.
//
// Print FLAT, no supports. Footprint ~86 x 56 mm.
// ============================================================================

include <common.scad>

bat       = [58, 32];   // [L, W] of your 4xAA holder footprint - MEASURE and adjust
WALL_H    = 8;          // retaining wall height
FLOOR_T   = 2.5;
BAT_Y_PITCH = 44;       // chassis y = 85 <-> 129
BAT_HOLE  = 3.6;        // oversized clearance for the inter-row tolerance

module battery_tray() {
    L = bat[0] + 2*WALL; W = bat[1] + 2*WALL;
    // floor must reach the 74 x 44 anchor rectangle + margin
    FL = max(L, ANCHOR_PITCH_X + 12);
    FW = max(W, BAT_Y_PITCH + 12);
    difference() {
        union() {
            translate([-FL/2, -FW/2, 0]) cube([FL, FW, FLOOR_T]);          // floor
            // pocket walls
            difference() {
                translate([-L/2, -W/2, 0]) cube([L, W, FLOOR_T + WALL_H]);
                translate([-bat[0]/2, -bat[1]/2, FLOOR_T])
                    cube([bat[0], bat[1], WALL_H + eps]);
            }
        }
        // 4 anchor mounting holes (74 x 44)
        for (sx = [-1,1], sy = [-1,1])
            translate([sx*ANCHOR_PITCH_X/2, sy*BAT_Y_PITCH/2, -eps])
                cylinder(d = BAT_HOLE, h = FLOOR_T + 2*eps);
        // floor lightening + wiring pass-through
        translate([0,0,-eps]) cylinder(d = 16, h = FLOOR_T + 2*eps);
        // zip-tie slots across the pocket floor
        for (sx = [-1,1]) translate([sx*bat[0]/4, 0, -eps])
            translate([-2, -bat[1]/2 - 1, 0]) cube([4, bat[1] + 2, FLOOR_T + 2*eps]);
    }
}

battery_tray();

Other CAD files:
mech/print/stl/chassis.stl
mech/print/boom.scad
mech/chassis.dxf
mech/print/chassis.scad
mech/print/common.scad
mech/print/rover_assembly.scad
mech/stacked_deck/coil_support.scad
mech/stacked_deck/corner_joint.scad
mech/stacked_deck/deck.scad
mech/stacked_deck/pillar.scad
mech/stacked_deck/seam_joint.scad
mech/stacked_deck/stack_assembly.scad

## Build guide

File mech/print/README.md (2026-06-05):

# 3D-printed parts — EEELunarRover

Parametric PLA parts for mounting the four sensor subsystems, the battery, and
the analogue perfboards onto the existing EEEBug V3.1 chassis. Source is
OpenSCAD (`.scad`); STLs are generated with `./render.sh`.

> The design intent, placement, weight budget and the physics behind every
> mounting decision live in [`../rover_layout.md`](../rover_layout.md). Read
> that first. This file is just the print/build mechanics.

## Why 3D-printed and modular

- **Modular** — each sensor subsystem is owned by a different team member. Every
  small mount shares one interface (2× M3 at 12 mm pitch), so a subsystem can be
  built, swapped or re-tuned without touching the others or re-cutting acrylic.
- **Bolts to real holes** — the boom and battery tray bolt to the chassis's
  existing M3 holes (measured from `../chassis.svg`): the four central anchors at
  x = 10.5 / 84.5 mm, y = 95 / 129 mm, which straddle the drive axle (y ≈ 105 mm).
- **Bed margin** — printer envelope is 200 × 200 × 200 mm PLA, but lab guidance
  is *don't use the full bed*. The largest part (the boom) is **86 × 127 mm**,
  comfortably inside a self-imposed 180 mm limit. Everything else is < 60 mm.

## Parts

| File / STL | What it is | Footprint | Key fit dimension |
|---|---|---|---|
| `boom.scad` → `boom.stl` | Front cantilever beam carrying the 3 down-facing sensors | 86 × 127 × 4 mm | anchors 74 mm; docks 12/20/12 mm |
| `sensor_mounts.scad` → `ir_shroud.stl` | Light-tight tube for the SFH 300 | Ø9 × 17 mm | bore **Ø6.0** (clears the 5 mm T-1¾ rim) |
| `sensor_mounts.scad` → `ultrasound_clamp.stl` | Clamp for the Murata MA40S4R | Ø13.3 × 9 mm | bore **Ø10.1** (MA40S4R = Ø9.9) |
| `sensor_mounts.scad` → `hall_pod.stl` | Pod holding the SS49E; reaches to the floor (front skid) | 18 × 12 × 33 mm | slot **4.5 × 2.1**; `postH` = Hall air-gap knob |
| `sensor_mounts.scad` → `antenna_bobbin.stl` | Former for the hand-wound 89 kHz coil (low profile) | Ø36 × 11 mm | core Ø22, 7 mm wind width, ears 42 mm |
| `perfboard_carrier.scad` → `perfboard_carrier_small.stl` | Sled for a Roth RE015 board | 40.5 × 40 mm | board 40.5 × 40, raised 5 mm |
| `perfboard_carrier.scad` → `perfboard_carrier_large.stl` | Sled for a Roth RE016 board | 68.6 × 68 mm | board 68.6 × 68 |
| `battery_tray.scad` → `battery_tray.stl` | Cradle for the 4×AA holder, over the axle | 86 × 46 mm | pocket 58 × 32 (**measure yours**) |

All sensor housings print **base-down, feature pointing up** (no supports). In
use the IR / ultrasound / Hall parts are flipped so the optics / transducer /
Hall face **down** toward the rock.

**Visualisation (not printed):** `chassis.scad` is the exact EEEBug outline
(auto-generated from `../chassis.svg`) and `rover_assembly.scad` combines it
with all the printed parts and representative blocks for the whole rover — open
either and press F5, or see `preview/rover_assembly*.png`.

## Rendering

```bash
cd mech/print
./render.sh            # writes stl/*.stl
```

`render.sh` uses headless `openscad -o`. (Note: it will not run inside a
restricted/sandboxed shell — the macOS OpenSCAD app needs a normal terminal —
but a plain Terminal session renders all eight STLs in a few seconds.)

To change a dimension, edit the variable at the top of the relevant `.scad`
(everything is parametric) or override on the command line, e.g. a bigger
battery pocket:

```bash
openscad -o stl/battery_tray.stl -D 'bat=[62,58]' battery_tray.scad
```

## Suggested print settings (PLA)

| Setting | Value | Why |
|---|---|---|
| Layer height | 0.2 mm | fast, strong enough |
| Perimeters | 4 | the boom is a cantilever — walls carry the load |
| Infill | 25 % | mass matters (750 g rover limit) |
| Supports | none | every part is designed support-free |
| Orientation | as modelled (flat) | best layer adhesion for the boom |

## Before you commit a print

1. **Measure your actual battery holder** and set `bat=[L,W]` in
   `battery_tray.scad`. The 58 × 32 default is a 2×2 AA box guess.
2. **Confirm the SFH 300 body height** with callipers (datasheet drawing was
   ambiguous at ~8.6 mm); lengthen the IR shroud tube if needed.
3. **Verify the chassis anchor holes** on the physical board — laser kerf makes
   internal holes ~0.1–0.2 mm larger than drawn; the Ø3.4 clearances allow for it.
4. **Print one `ir_shroud` first** as a fit test for the M3 clearances and the
   sensor bore before committing the long boom print.

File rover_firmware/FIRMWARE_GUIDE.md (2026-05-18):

# Firmware Walkthrough

For the embedded lead. This document walks through `src/main.cpp` section by section so you can read, modify, and defend the firmware at the interim interview and demo.

The demo examiner will ask you questions like "why a 500 ms watchdog?", "why JSON?", "what happens if the WiFi drops mid-drive?". You'll be expected to answer those without notes. This guide is so you can.

---

## 1. What the firmware does, in one paragraph

It connects the Metro M0 to the lab WiFi at a fixed IP, runs a small HTTP server on port 80, and answers five endpoints. Two of them are state-changing (`/drive`, `/stop`) and write to motor PWM pins via the H-bridge module. Three are read-only (`/info`, `/status`, `/scan`) and return JSON describing the rover's current state or a snapshot of sensor readings. A watchdog in `loop()` zeros the motors if no drive heartbeat arrives within 500 ms, so the rover stops when WiFi drops or the operator releases a key.

---

## 2. Walk through `src/main.cpp`

The file is organised as labelled sections separated by `// =====...` banners. Read top-to-bottom.

### 2.1 Includes and macros

```cpp
#define USE_WIFI_NINA  false
#define USE_WIFI101    true
#include <WiFiWebServer.h>
#include <ArduinoJson.h>
```

The two `#define`s tell `WiFiWebServer.h` which underlying WiFi driver to compile against. The Metro M0 uses the WINC1500 shield, which is driven by the `WiFi101` library, so we set `USE_WIFI101 = true`.

`ArduinoJson` is used to build the JSON responses. We use v6.x (see `platformio.ini`), which uses `StaticJsonDocument<N>` where `N` is the buffer capacity in bytes.

### 2.2 Configuration block

```cpp
const char ssid[]      = "EEERover";
const char pass[]      = "exhibition";
const int  groupNumber = 0;
```

Set `groupNumber` to your team number. `WiFi.config(IPAddress(192,168,0,groupNumber+1))` in `setup()` reserves that static IP on the lab WiFi.

```cpp
const int LEFT_DIR_PIN = 4;
const int LEFT_PWM_PIN = 3;
...
```

These are the digital pins wired to the H-bridge module. Verify them against your actual wiring **before flashing with motors connected**. Pins 5, 7, and 10 must not be reused because the WiFi shield uses them for CS, IRQ, and RST respectively.

```cpp
const unsigned long DRIVE_WATCHDOG_MS = 500;
```

The watchdog window. The UI re-sends `/drive` every 150 ms while a direction key is held, so 500 ms gives roughly 3x headroom for jitter.

### 2.3 Motor control helpers

```cpp
static void applyMotor(int pwmPin, int dirPin, int command);
```

Takes a signed integer in `[-255, 255]`. Sets `dirPin` HIGH for forward, LOW for reverse, and writes the absolute value to `pwmPin` via `analogWrite()`. This matches the H-bridge module's logic: DIR picks direction, PWM picks magnitude.

```cpp
static void applyDrive();
```

Applies the current `driveLeft` and `driveRight` to both motors. Also drives the onboard LED so you can sanity-check that drive commands arrived without needing a multimeter.

```cpp
static void stopMotors();
```

Convenience: zero both motors and call `applyDrive()`.

### 2.4 State machine

```cpp
enum RoverState { ST_IDLE, ST_DRIVING, ST_SCANNING, ST_ERROR };
```

The state machine lives in the firmware (see section 4.2 of `../CONTROLLER_PLAN.md`). The UI just renders whatever string we publish. The current state is *derived* on every `/status` call from three facts:

- Is a scan currently in progress? Then `scanning`.
- Are either motor PWMs non-zero? Then `driving`.
- Otherwise: `idle`.

This means we don't need to track transitions explicitly. Less state to keep consistent equals fewer bugs.

`ST_ERROR` is reported whenever the WiFi link is down (`wifiUp == false`). In practice the UI cannot fetch `/status` while WiFi is down, so this state is mostly observed in the brief window if the link recovers between a drop and the next poll.

### 2.5 Sensor stubs

```cpp
static AgeResult readAge() {
  return { String("#317"), true };
}
```

Each `readX()` returns a small struct that includes both a value and a `valid` flag. The valid flag lets the UI grey out stale or never-acquired readings instead of showing rubbish.

**These are stubs.** Each subsystem owner replaces the body of their function with real hardware logic when their analogue front-end is ready. The function signatures must not change, or the JSON shape breaks and the UI breaks with it.

### 2.6 JSON helpers

```cpp
static void sendJson(int code, JsonDocument& doc);
```

Serialises the document into a **fixed 512-byte stack buffer**, adds CORS and cache-control headers, and sends the response. Used by every route handler.

It deliberately does not build a heap `String`. A new `String` allocation on every request, several times a second for hours, would fragment the small (32 KB) heap. A fixed stack buffer has no such cost and is freed automatically when the function returns. 512 bytes comfortably holds the largest response (`/status`, around 250 bytes).

The CORS header (`Access-Control-Allow-Origin: *`) is what lets the UI hosted on the operator's laptop talk to the rover's IP. Without it the browser would refuse to read responses from a different origin.

### 2.7 Route handlers

Each handler is named `handleX` and registered in `setup()` with `server.on("/x", handleX)`. They follow the same pattern:

1. Parse query args if any.
2. Read state or sensor data.
3. Build a `StaticJsonDocument`.
4. Call `sendJson(200, doc)`.

`handleDrive` is the one that mutates state: it updates `driveLeft`, `driveRight`, `lastDriveMs`, and calls `applyDrive()`.

`handleScan` is special because it blocks for ~600 ms. During that time we still need the HTTP server to be responsive to keep the connection alive, so the wait loop calls `delay(10)` in increments rather than `delay(600)` in one go. We also call `stopMotors()` at the start because shaking the rover during a measurement makes the readings worse.

### 2.8 Status LED and WiFi helper

`updateLed()` drives the onboard LED as the only diagnostic when no USB cable is attached: **fast blink** when WiFi is down, **solid** while driving, **off** when idle and connected. It is called once per `loop()`.

`connectWiFi(maxAttempts)` tries to join the network up to `maxAttempts` times, returning `true` on success. It is **bounded** on purpose. The starter sketch loops on `WiFi.begin()` forever, so a wrong password or an absent network hangs the board silently with no clue why. Bounding it means `setup()` can move on and `loop()` can keep retrying.

### 2.9 `setup()`

Standard Arduino flow:

1. Configure pin modes.
2. Open the serial port at 9600 baud (with a 5 s timeout in case there's no USB attached).
3. Check the WiFi shield is present; if absent, halt while blinking the LED fast so the failure is visible.
4. Set the static IP if `groupNumber` is non-zero.
5. Call `connectWiFi(20)` - up to twenty attempts, then continue regardless.
6. Register all the route handlers.
7. Start the server.

If WiFi fails here, the board still starts the server and `loop()` keeps retrying. It never hangs.

### 2.10 `loop()`

Three pieces of work:

1. **WiFi health check** (every 3 s). If the link has dropped, stop the motors immediately (the rover must not move while it cannot be controlled), then attempt a few quick reconnects. On success, re-`begin()` the server so it listens again.
2. **`server.handleClient()`** services any pending HTTP request.
3. **The watchdog check**. If motors are commanded non-zero and the last `/drive` was more than 500 ms ago, stop the motors. Combined with the WiFi check, this is the rover's safety story: a dropped connection stops it within at most 500 ms via the watchdog, and the health check stops it again and keeps it stopped until control is restored.

Then `updateLed()` refreshes the status LED.

---

## 3. Likely demo questions and how to answer them

**Why 500 ms for the watchdog?**
The UI re-sends `/drive` every 150 ms while a direction key is held. 500 ms gives roughly 3x margin for network jitter and lost packets. Smaller would risk false stops, larger would let the rover keep running too long after a real fault.

**Why is the state machine on the firmware, not the UI?**
Because every event that triggers a state transition is something only the firmware can observe directly: a drive command arrived, the watchdog fired, a scan finished. If the UI tracked state independently, a page refresh would lose it.

**Why classification on the UI, not the firmware?**
Classification rules might change. Putting them in JS means we can edit them without re-flashing the Metro. Firmware just publishes raw sensor readings.

**Why JSON for `/status`?**
Self-describing, trivially parsed in JavaScript, easy to debug with `curl`. The overhead vs. a delimited string is acceptable on a `WiFi101` link.

**What happens if WiFi drops while I'm holding W?**
Two layers catch it. First, the next `/drive` heartbeat fails to reach the rover, so 500 ms later the drive watchdog fires and `stopMotors()` runs. Second, within 3 s the WiFi health check in `loop()` notices the link is down, stops the motors again, and starts re-attempting the connection. The rover stays stopped until the link is back and the UI resumes heartbeats.

**Why serialise JSON into a buffer instead of a String?**
A `String` allocates on the heap. Building one per response, several times a second, fragments the 32 KB heap over a long demo and can eventually cause allocation failures. A fixed stack buffer has no allocation cost and is reclaimed when the function returns.

**Why bound the WiFi connection attempts?**
The starter sketch loops on `WiFi.begin()` forever. If the password is wrong or the network is down, the board hangs in `setup()` with no indication. Bounding the attempts lets the board start anyway, blink the LED to show WiFi is down, and keep retrying from `loop()`.

**Why is `/scan` blocking?**
Single-threaded server. The simpler architecture is worth the brief blocking. The UI handles it by disabling the Scan button and showing "Scanning..." during the call. We could make it async by starting a measurement in `/scan`, returning an ID, and polling `/scan/<id>` for completion, but that's overkill for one rock-at-a-time operation.

**How would you add another sensor?**
Add a `readX()` stub in the sensor section, add the corresponding field to the JSON shape in `handleStatus()` and `handleScan()`, update the API contract in `CONTROLLER_PLAN.md`, and tell the UI lead. Then implement the analogue front-end and replace the stub body.

**What if the H-bridge module needs more than 3.3 V on its inputs?**
Most H-bridge logic-level inputs accept 3.3 V as a valid HIGH because they have CMOS inputs with thresholds around 1.5 V. Check the module datasheet. If not, use a level shifter or a transistor-based interface.

**What's the worst case current draw on the digital outputs?**
The H-bridge inputs are high-impedance, so almost zero. The motors themselves are driven from the EEEBug battery rail through the H-bridge, not through the Metro pins.

---

## 4. Tasks to do before the interim

In rough order:

1. **Read the code end-to-end.** Open `src/main.cpp`, follow the section banners. If anything is unclear, ask before flashing.
2. **Pick correct motor pins** for your physical wiring. Update the constants in `src/main.cpp`. Verify with a multimeter that the WiFi shield's pins (5, 7, 10) aren't being reused.
3. **First flash, no motors.** Power the Metro via USB only, flash, watch the serial monitor for the IP address. Run `curl http://<ip>/info` from a laptop on the same WiFi and confirm you get JSON back.
4. **Smoke-test driving.** With motors still disconnected, call `curl "http://<ip>/drive?l=128&r=128"` and verify the onboard LED comes on. Wait 500 ms and verify it goes off (watchdog). Call `curl http://<ip>/stop` and verify it goes off immediately.
5. **Wire one motor.** Hook just the left motor up to the H-bridge channel for `LEFT_*_PIN`. Power the EEEBug battery rail. Run a drive command and observe the wheel turning at the commanded direction and speed. Repeat for the right motor.
6. **Open the UI** at `http://localhost:8080/?api=http://<ip>` and verify the drive D-pad now spins your wheels.
7. **Hand the file to each sensor owner.** Show them their `readX()` function. They replace the body, you re-flash. The UI lights up sensor by sensor as they come online.

---

## 5. Files you own as the embedded lead

- `rover_firmware/src/main.cpp` - all the firmware
- `rover_firmware/platformio.ini` - build config and library deps
- `rover_firmware/README.md` - build/flash instructions
- `rover_firmware/FIRMWARE_GUIDE.md` - this file

The UI side (`../UI/`) and the project-level docs (`../CONTROLLER_PLAN.md`, `../PROJECT_SUMMARY.md`) belong to the UI lead. If you propose changes to the HTTP contract, take it up with them - both files have to move in lockstep.

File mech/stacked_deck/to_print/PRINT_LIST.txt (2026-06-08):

EEELunarRover - Stacked-deck chassis : 3D PRINT LIST
Group 9, ELEC40006

Printer: 200 x 200 x 200 mm, PLA. Every part fits well inside the bed.

FILES TO PRINT  (4 files, 9 parts total = one complete rover / two stacked decks)
================================================================================

  File                 Qty   Size            Notes
  ------------------   ---   -------------   ------------------------------------
  deck_half_A.stl       2    ~122 x 95 mm    front half of a deck
  deck_half_B.stl       2    ~102 x 95 mm    rear half of a deck
                                             >> PRINT UPSIDE-DOWN (flip in the
                                                slicer) so the overlap ledge
                                                sits flat on the bed
  pillar.stl            4    O10 x 50 mm     corner stacking pillars
  coil_support.stl      1    ~127 x 91 mm    coil ring + sensor perfboard tray

  TOTAL: 9 parts

WHY TWO HALVES PER DECK
================================================================================
A full deck is 204 mm long - longer than the 200 mm printer - so each deck
prints as half A + half B. The halves overlap (a half-lap) and bolt together
with 2 screws to make one flush 204 mm deck.

SUGGESTED PRINT SETTINGS (PLA)
================================================================================
  Layer height : 0.2 mm
  Perimeters   : 4
  Infill       : 25 %
  Supports     : none (all parts are designed to print without support)
  Orientation  : flat as exported, EXCEPT deck_half_B = upside-down

DO NOT PRINT
================================================================================
  deck_full.stl  - reference only (the whole 204 mm deck, too long for the bed).
                   It is not in this folder; do not print it if you see it.

ASSEMBLY (for reference - not needed to print)
================================================================================
  - 2 decks : each = deck_half_A + deck_half_B overlapped, 2x M3 screws.
  - 4 pillars between the decks : one M3 screw through each deck corner hole
    self-taps into the pillar end.
  - coil_support : screws onto one deck with 4x M3.
  Fasteners needed : M3 screws ~8-10 mm (self-tap into PLA) + a few M3 nuts.

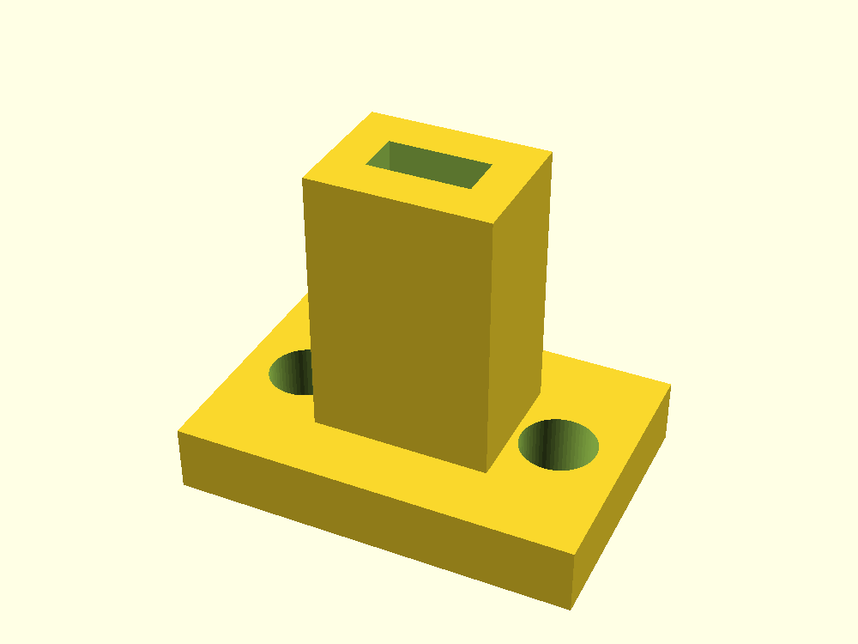
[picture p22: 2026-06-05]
mech/print/preview/hall_pod.png

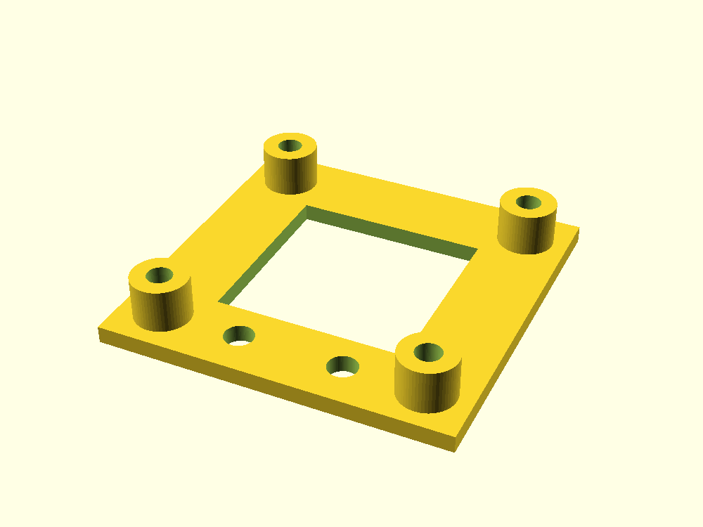
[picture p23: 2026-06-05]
mech/print/preview/perfboard_carrier.png

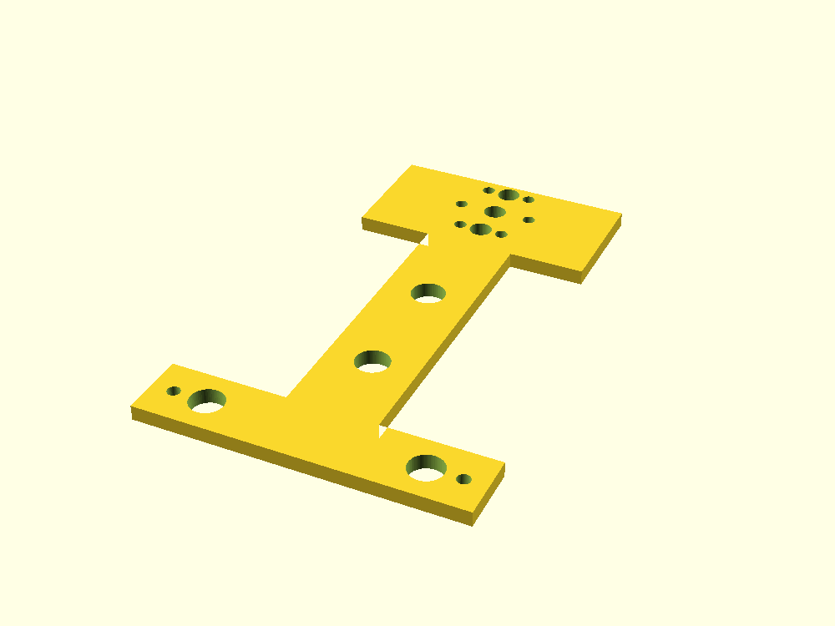
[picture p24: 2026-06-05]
mech/print/preview/boom.png

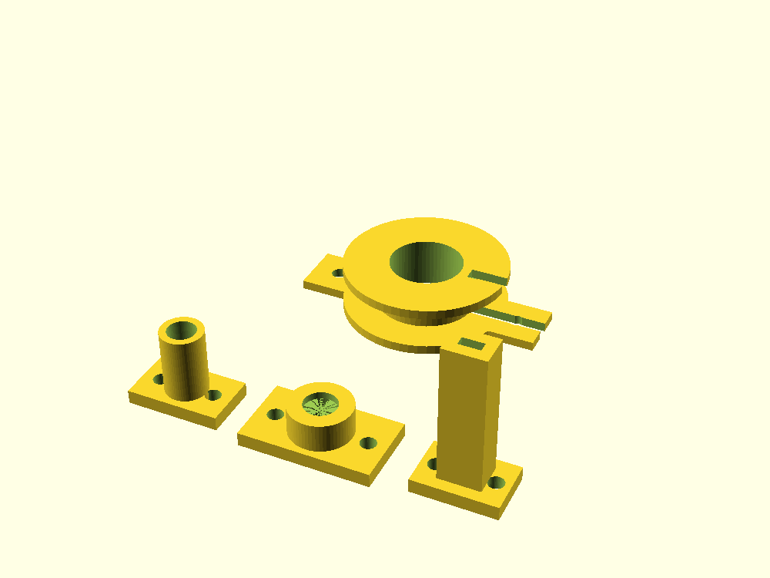
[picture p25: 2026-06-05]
mech/print/preview/sensor_mounts_all.png

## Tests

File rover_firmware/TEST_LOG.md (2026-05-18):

# Firmware Test Log

Hardware testing record for the EEELunarRover firmware.

**Hardware under test:** Adafruit Metro M0 Express + WINC1500 WiFi shield
**Toolchain:** PlatformIO 6.1.19, framework-arduino-samd-adafruit 1.7.16, gcc-arm-none-eabi 9.3.1
**Firmware:** `rover_firmware/src/main.cpp` (v0.2.0)

---

## 2026-05-18 - Session 1: compile and bench flash

### Build verification

| Step | Result |
| --- | --- |
| Install PlatformIO | OK (6.1.19) |
| `pio run` attempt 1 | FAILED. Bundled `Adafruit_TinyUSB_Arduino` would not compile because no USB stack was selected. |
| Fix attempt: `lib_ignore` | Ineffective. The library is bundled in the core, not LDF-discovered. |
| Fix: `build_flags = -DUSE_TINYUSB` in `platformio.ini` | Resolved the TinyUSB error. |
| `pio run` attempt 2 | FAILED. `WiFi.localIP().toString()` - WiFi101's `localIP()` returns a raw `uint32_t`, not an `IPAddress`. |
| Fix attempt: `IPAddress(WiFi.localIP()).toString()` | FAILED. This SAMD core's `IPAddress` has no `toString()`. |
| Fix: format the dotted-quad manually with `snprintf` from `IPAddress` octets | Resolved. |
| `pio run` attempt 3 | SUCCESS. RAM 22.2%, Flash 32.3%. |

Firmware was then improved (bounded WiFi connect with reconnect, JSON serialised into a fixed stack buffer, LED status feedback, larger JSON document sizes) and recompiled: SUCCESS, RAM 22.2%, Flash 32.4%.

### Flash to hardware

| Step | Result |
| --- | --- |
| Metro M0 detected | `/dev/cu.usbmodem21201`, USB ID 239A:8013 |
| `pio run -t upload` attempt 1 | FAILED at ~4%, "SAM-BA operation failed". |
| Observation | Board left in bootloader mode (USB ID changed to 239A:0013). |
| `pio run -t upload` retry | SUCCESS. 1326/1326 pages written, verify successful. |

Note: the SAM-BA upload failing on the first attempt and succeeding on retry was repeatable across both flash sessions. The retry works because the board is already sitting in the bootloader after the failed write.

### First boot - lab WiFi (EEERover)

| Check | Result |
| --- | --- |
| Serial boot output | `Connecting to EEERover` / `IP: 192.168.0.112` / `HTTP server running` |
| WiFi association | OK. DHCP address 192.168.0.112. |
| HTTP API from the laptop | NOT TESTED. The laptop was not on the EEERover network. |

### Issue: laptop / rover network mismatch

The rover joined `EEERover`. The laptop was not on a matching network (its Wi-Fi interface `en0` reported `192.0.0.2`, not associated with EEERover). The laptop and rover must share one network to communicate.

Resolution chosen: move both devices onto a phone hotspot, so the hotspot's cellular link also keeps the development laptop online during testing.

### Re-flash - hotspot

| Step | Result |
| --- | --- |
| `ssid` / `pass` changed to the hotspot (local change, must NOT be committed) | Done |
| `pio run -t upload` | FAILED first attempt, SUCCESS on retry (same SAM-BA pattern). |
| Rover IP on the hotspot | `172.20.10.6`. Serial: `Connecting to Josh (2)` / `IP: 172.20.10.6` / `HTTP server running`. |

### HTTP API test - hotspot

Laptop joined `Josh (2)` (address `172.20.10.5`); rover at `172.20.10.6`. All endpoints exercised with `curl` from the laptop:

| Endpoint | Request | Response | Result |
| --- | --- | --- | --- |
| `/info` | GET | `{"group":0,"ip":"172.20.10.6","fw_version":"0.2.0"}` | PASS |
| `/status` | GET | full JSON: `drive`, `sensors`, `state":"idle"` | PASS |
| `/drive` | `?l=200&r=200` | `{"drive":{"left":200,"right":200}}` | PASS |
| `/stop` | GET | `{"stopped":true}` | PASS |
| `/scan` | GET | `{"age":"#317","ir_rate_hz":547,"ultrasound_present":true,"magnet":"up","classification":null}` | PASS |

Sensor values are the firmware stub defaults (age `#317`, IR 547 Hz, ultrasound present, magnet up), as expected with no analogue hardware connected.

Watchdog observed: a single `/drive` request with no follow-up heartbeat caused the motors to auto-stop roughly 500 ms later (LED solid briefly, then off), confirming the 500 ms drive watchdog. The operator UI sends heartbeats every 150 ms, so under normal driving the LED stays solid.

### Motor wiring and drive test

Motor driver: dual H-bridge module, wired to the Metro as below. Firmware pin constants updated to match and re-flashed.

| Signal | Metro pin |
| --- | --- |
| Right motor direction | D4 |
| Right motor enable (PWM) | D9 |
| Left motor direction | D12 |
| Left motor enable (PWM) | D6 |

USB issue during this re-flash: after a failed SAM-BA upload the board stopped enumerating on USB entirely (no serial port, nothing in the USB registry) even though the bootloader LED was breathing. Recovered by **double-tapping the RESET button**, which re-initialised the bootloader USB and brought the port back. Worth knowing: if the board vanishes from USB during flashing, double-tap reset.

Drive test: rover on the hotspot, operator console pointed at it, holding the drive controls spun the motors. **The full control path is verified end to end: console -> WiFi -> firmware -> H-bridge -> motors.**

---

## Outstanding

- [x] Capture the rover's IP on the hotspot - `172.20.10.6`
- [x] HTTP API test from the laptop - all five endpoints PASS
- [x] Onboard LED - watchdog auto-stop observed (solid then off); full WiFi-down blink not yet checked
- [x] Point the operator UI at the real rover
- [x] Test `/drive` with motors physically wired - motors spin, full control path verified
- [ ] Confirm each motor's direction is correct (forward = forward); flip `DIR` logic for any reversed motor
- [ ] Replace sensor stubs with real subsystem code as each comes online
- [ ] Revert `ssid` / `pass` to `EEERover` / `exhibition` before committing

## Notes for the report

- The SAM-BA first-attempt failure is a known PlatformIO + SAMD bootloader quirk, worth a sentence in the evaluation section as a build-process observation.
- Compiling cleanly is necessary but not sufficient; two genuine API bugs (`USE_TINYUSB`, `localIP()`) only surfaced at compile time, and runtime behaviour (WiFi, motors, sensors) still needs separate verification on hardware.

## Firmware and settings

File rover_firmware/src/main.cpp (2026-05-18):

/*
 * EEELunarRover firmware
 * Target: Adafruit Metro M0 Express + WINC1500 WiFi shield
 *
 * Implements the HTTP API contract from ../../CONTROLLER_PLAN.md:
 *   GET /info                  -> { t, group, ip, fw_version }
 *   GET /status                -> { t, drive, sensors, battery_mv, state }
 *   GET /drive?l=<int>&r=<int> -> set motor PWMs in [-255, 255]; refreshes watchdog
 *   GET /stop                  -> immediately zero both motors
 *   GET /scan                  -> blocking measurement cycle (~600 ms), returns snapshot
 *
 * Robustness:
 *   - 500 ms drive watchdog auto-stops the motors if /drive heartbeats stop.
 *   - WiFi connection is bounded (it never hangs forever) and is re-attempted
 *     from loop() if it drops. Motors are stopped whenever WiFi is down.
 *   - JSON responses serialise into a fixed stack buffer, so there is no
 *     per-request heap allocation to fragment memory over a long demo.
 *   - The onboard LED reports status when no serial cable is attached:
 *       fast blink = WiFi down,  solid = driving,  off = idle.
 *
 * Sensor stubs (readAge / readIR / readUltrasound / readMagnet) currently
 * return plausible fake data so the UI can be tested end-to-end. Each sensor
 * subsystem owner replaces the body of their function with real hardware logic.
 *
 * IMPORTANT: pins 5, 7, 10 are reserved by the WiFi shield. Do NOT use them
 * for any other purpose.
 */

#define USE_WIFI_NINA  false
#define USE_WIFI101    true
#include <WiFiWebServer.h>
#include <ArduinoJson.h>

// ===================== Configuration =====================

const char ssid[]      = "EEERover";
const char pass[]      = "exhibition";
const int  groupNumber = 0;        // CHANGE ME: sets static IP to 192.168.0.<groupNumber+1>
const char fwVersion[] = "0.2.0";

// Motor driver pins, set to match the dual H-bridge wiring.
// Each motor has a direction line and an enable line; the enable line
// takes the PWM signal for speed control.
// Pins 5, 7, 10 are reserved by the WiFi shield.
const int LEFT_DIR_PIN   = 12;   // left motor direction
const int LEFT_PWM_PIN   = 6;    // left motor enable (PWM)
const int RIGHT_DIR_PIN  = 4;    // right motor direction
const int RIGHT_PWM_PIN  = 9;    // right motor enable (PWM)
const int DEBUG_LED_PIN  = LED_BUILTIN;

// Drive watchdog: if no /drive heartbeat for this long, motors auto-stop.
const unsigned long DRIVE_WATCHDOG_MS = 500;

// Approximate length of a scan cycle. Real IR pulse counting will want
// at least a few hundred ms to integrate enough events to discriminate
// the two Poisson rates (312 vs 547 s^-1).
const unsigned long SCAN_DURATION_MS = 600;

// How often loop() checks the WiFi link is still up.
const unsigned long WIFI_CHECK_MS = 3000;

// ===================== State =====================

enum RoverState { ST_IDLE, ST_DRIVING, ST_SCANNING, ST_ERROR };

int  driveLeft  = 0;
int  driveRight = 0;
unsigned long lastDriveMs = 0;
bool scanRunning = false;
bool wifiUp = false;

WiFiWebServer server(80);

// ===================== Motor control =====================

static void applyMotor(int pwmPin, int dirPin, int command)
{
  command = constrain(command, -255, 255);
  if (command >= 0) {
    digitalWrite(dirPin, HIGH);
    analogWrite(pwmPin, command);
  } else {
    digitalWrite(dirPin, LOW);
    analogWrite(pwmPin, -command);
  }
}

static void applyDrive()
{
  applyMotor(LEFT_PWM_PIN,  LEFT_DIR_PIN,  driveLeft);
  applyMotor(RIGHT_PWM_PIN, RIGHT_DIR_PIN, driveRight);
}

static void stopMotors()
{
  driveLeft = 0;
  driveRight = 0;
  applyDrive();
}

static RoverState currentRoverState()
{
  if (!wifiUp)     return ST_ERROR;
  if (scanRunning) return ST_SCANNING;
  if (driveLeft != 0 || driveRight != 0) return ST_DRIVING;
  return ST_IDLE;
}

static const char* stateName(RoverState s)
{
  switch (s) {
    case ST_IDLE:     return "idle";
    case ST_DRIVING:  return "driving";
    case ST_SCANNING: return "scanning";
    case ST_ERROR:    return "error";
  }
  return "unknown";
}

// ===================== Status LED =====================
//
// The onboard LED is the only feedback available when the board runs without
// a USB cable attached:
//   fast blink = WiFi down,  solid = driving,  off = idle and connected.

static void updateLed()
{
  bool on;
  if (!wifiUp) {
    on = (millis() / 150) % 2;            // fast blink while disconnected
  } else {
    on = (driveLeft != 0 || driveRight != 0);
  }
  digitalWrite(DEBUG_LED_PIN, on ? HIGH : LOW);
}

// ===================== Sensor stubs (to be replaced) =====================
//
// Each sensor subsystem owner replaces the body of their function with the
// real hardware read. Keep the return shape the same so the JSON contract
// does not change.
//
// While stubs are in place, /status returns the placeholder values defined
// here. This lets the UI lead develop and test their side end-to-end before
// any analogue hardware is built.

struct AgeResult { String value; bool valid; };
static AgeResult readAge() {
  // TODO (radio owner): return the most recently decoded 4-char age string
  // from the UART buffer. Set valid=false until a complete "#NNN" arrives.
  return { String("#317"), true };
}

struct IRResult { int rateHz; bool valid; };
static IRResult readIR() {
  // TODO (IR owner): return pulses per second over the latest measurement
  // window. The rates to distinguish are ~312 and ~547 s^-1.
  return { 547, true };
}

struct UltrasoundResult { bool present; bool valid; };
static UltrasoundResult readUltrasound() {
  // TODO (ultrasound owner): return true if the 40 kHz tone is detected
  // above the threshold; false otherwise.
  return { true, true };
}

struct MagnetResult { const char* direction; bool valid; };
static MagnetResult readMagnet() {
  // TODO (magnet owner): return "up" or "down" depending on the polarity
  // of the static magnetic field at the sensor.
  return { "up", true };
}

static int readBatteryMv() {
  // TODO: read battery voltage via a divider on an analogue pin.
  // Leave constant for now so the UI battery indicator is at least defined.
  return 7200;
}

// ===================== HTTP helpers =====================

static void sendJson(int code, JsonDocument& doc)
{
  // Serialise into a fixed stack buffer. This avoids allocating a String on
  // the heap for every request, which would fragment memory over a long run.
  // 512 bytes comfortably holds the largest response (/status, ~250 bytes).
  char buf[512];
  serializeJson(doc, buf, sizeof(buf));
  // CORS: allow the UI to be served from a different origin (e.g. laptop).
  server.sendHeader(F("Access-Control-Allow-Origin"), F("*"));
  server.sendHeader(F("Cache-Control"),               F("no-store"));
  server.send(code, F("application/json"), buf);
}

// ===================== Route handlers =====================

static void handleInfo()
{
  StaticJsonDocument<256> doc;
  doc[F("t")]     = millis();
  doc[F("group")] = groupNumber;

  // WiFi101's localIP() returns a raw uint32_t and this core's IPAddress
  // has no toString(), so format the dotted-quad manually.
  IPAddress ip(WiFi.localIP());
  char ipbuf[16];
  snprintf(ipbuf, sizeof(ipbuf), "%d.%d.%d.%d", ip[0], ip[1], ip[2], ip[3]);
  doc[F("ip")] = ipbuf;

  doc[F("fw_version")] = fwVersion;
  sendJson(200, doc);
}

static void handleStatus()
{
  StaticJsonDocument<512> doc;
  doc[F("t")] = millis();

  JsonObject drive = doc.createNestedObject(F("drive"));
  drive[F("left")]  = driveLeft;
  drive[F("right")] = driveRight;

  JsonObject sensors = doc.createNestedObject(F("sensors"));

  AgeResult age = readAge();
  if (age.valid) sensors[F("age")] = age.value;
  else           sensors[F("age")] = nullptr;
  sensors[F("age_valid")] = age.valid;

  IRResult ir = readIR();
  sensors[F("ir_rate_hz")] = ir.rateHz;
  sensors[F("ir_valid")]   = ir.valid;

  UltrasoundResult us = readUltrasound();
  sensors[F("ultrasound_present")] = us.present;
  sensors[F("ultrasound_valid")]   = us.valid;

  MagnetResult m = readMagnet();
  sensors[F("magnet")]       = m.direction;
  sensors[F("magnet_valid")] = m.valid;

  doc[F("battery_mv")] = readBatteryMv();
  doc[F("state")]      = stateName(currentRoverState());

  sendJson(200, doc);
}

static void handleDrive()
{
  if (!server.hasArg(F("l")) || !server.hasArg(F("r"))) {
    StaticJsonDocument<96> err;
    err[F("error")] = F("missing l or r");
    sendJson(400, err);
    return;
  }
  int l = server.arg(F("l")).toInt();
  int r = server.arg(F("r")).toInt();
  driveLeft   = constrain(l, -255, 255);
  driveRight  = constrain(r, -255, 255);
  lastDriveMs = millis();
  applyDrive();

  StaticJsonDocument<128> doc;
  doc[F("t")] = millis();
  JsonObject d = doc.createNestedObject(F("drive"));
  d[F("left")]  = driveLeft;
  d[F("right")] = driveRight;
  sendJson(200, doc);
}

static void handleStop()
{
  stopMotors();
  StaticJsonDocument<96> doc;
  doc[F("t")]       = millis();
  doc[F("stopped")] = true;
  sendJson(200, doc);
}

static void handleScan()
{
  // While scanning, motors should be stopped so the antenna and sensors
  // aren't shaken about.
  stopMotors();

  scanRunning = true;

  // Blocking measurement window. The HTTP server does not service other
  // requests during this ~600 ms. That is acceptable here: the operator
  // scans one rock at a time and the UI shows a "Scanning" state meanwhile.
  // A more advanced version could count IR pulses across this window.
  delay(SCAN_DURATION_MS);

  AgeResult        age = readAge();
  IRResult         ir  = readIR();
  UltrasoundResult us  = readUltrasound();
  MagnetResult     m   = readMagnet();

  scanRunning = false;

  StaticJsonDocument<384> doc;
  doc[F("t")] = millis();
  if (age.valid) doc[F("age")] = age.value;
  else           doc[F("age")] = nullptr;
  doc[F("ir_rate_hz")]         = ir.rateHz;
  doc[F("ultrasound_present")] = us.present;
  doc[F("magnet")]             = m.direction;
  doc[F("classification")]     = nullptr;  // classification is done in the UI
  sendJson(200, doc);
}

static void handleNotFound()
{
  StaticJsonDocument<192> doc;
  doc[F("error")] = F("not found");
  doc[F("uri")]   = server.uri();
  sendJson(404, doc);
}

// ===================== WiFi =====================

// Attempt to join the network, up to maxAttempts tries. Returns true on
// success. Bounded so the rover never hangs forever on a bad connection.
static bool connectWiFi(uint8_t maxAttempts)
{
  for (uint8_t i = 0; i < maxAttempts; i++) {
    if (WiFi.begin(ssid, pass) == WL_CONNECTED) return true;
    Serial.print('.');
    delay(500);
  }
  return false;
}

// ===================== Setup / loop =====================

void setup()
{
  pinMode(DEBUG_LED_PIN,  OUTPUT);
  pinMode(LEFT_DIR_PIN,   OUTPUT);
  pinMode(LEFT_PWM_PIN,   OUTPUT);
  pinMode(RIGHT_DIR_PIN,  OUTPUT);
  pinMode(RIGHT_PWM_PIN,  OUTPUT);
  digitalWrite(DEBUG_LED_PIN, LOW);
  stopMotors();

  Serial.begin(9600);
  // Wait up to 5 s for USB serial so startup messages are visible if attached.
  while (!Serial && millis() < 5000) {}
  Serial.println(F("\nEEELunarRover firmware starting"));

  if (WiFi.status() == WL_NO_SHIELD) {
    Serial.println(F("WiFi shield not present - halting"));
    while (true) {                         // blink fast so the halt is visible
      digitalWrite(DEBUG_LED_PIN, (millis() / 100) % 2);
    }
  }

  if (groupNumber) {
    WiFi.config(IPAddress(192, 168, 0, groupNumber + 1));
  }

  Serial.print(F("Connecting to "));
  Serial.print(ssid);
  wifiUp = connectWiFi(20);
  Serial.println();
  if (wifiUp) {
    Serial.print(F("IP: "));
    Serial.println(static_cast<IPAddress>(WiFi.localIP()));
  } else {
    Serial.println(F("WiFi not connected - will keep retrying in loop()"));
  }

  server.on(F("/info"),   handleInfo);
  server.on(F("/status"), handleStatus);
  server.on(F("/drive"),  handleDrive);
  server.on(F("/stop"),   handleStop);
  server.on(F("/scan"),   handleScan);
  server.onNotFound(handleNotFound);

  server.begin();
  Serial.println(F("HTTP server running"));
}

void loop()
{
  // --- WiFi health: re-attempt if dropped; never drive while uncontrolled ---
  static unsigned long lastWifiCheck = 0;
  if (millis() - lastWifiCheck > WIFI_CHECK_MS) {
    lastWifiCheck = millis();
    if (WiFi.status() != WL_CONNECTED) {
      if (wifiUp) Serial.println(F("WiFi lost - stopping motors, reconnecting"));
      wifiUp = false;
      stopMotors();
      if (connectWiFi(4)) {
        wifiUp = true;
        server.begin();   // best-effort: re-listen after the link returns
        Serial.println(F("WiFi reconnected"));
      }
    } else {
      wifiUp = true;
    }
  }

  server.handleClient();

  // --- 500 ms drive watchdog ---
  if ((driveLeft != 0 || driveRight != 0)
      && (millis() - lastDriveMs > DRIVE_WATCHDOG_MS)) {
    stopMotors();
  }

  updateLed();
}

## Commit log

2026-05-18 Add EEELunarRover controller subsystem: firmware, operator UI, docs
    Firmware (Metro M0 + WINC1500): WiFi HTTP server implementing the
    /info, /status, /drive, /stop and /scan API; H-bridge motor control
    with a 500 ms drive watchdog; bounded WiFi connect with auto-reconnect;
    stubs for the four analogue sensor subsystems. Verified compiling and
    running on real hardware.
    Operator UI: browser console with gamepad, keyboard and on-screen
    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
2026-05-18 Reorganise into the group repo's UI/ and rover_firmware/ layout
    Rename firmware/ to rover_firmware/ and ui/ to UI/ to match the
    folder structure already present on the group repository, and fix
    the path references in the docs accordingly.
    [main.cpp]
2026-05-18 Document motor driver pin map; correct firmware README pins
    Fill in hardware/pin_map.md with the dual H-bridge wiring (D12/D6/D4/D9)
    and the WiFi-shield reserved pins. Correct the rover_firmware README's
    pin table to the current, hardware-tested values.
2026-06-05 Add mechanical & sensor design: rover layout, 3D-printed mounts, BOM
    Full mounting/layout design for the four sensor subsystems plus the parts
    to order. Centre-axle layout: sensors on a front boom away from the motors,
    Hall pod reaching toward the floor, battery over the axle, Metro at the rear.
    - mech/rover_layout.md: master design doc (layout, weight budget, keep-outs)
    - mech/print/: parametric OpenSCAD parts + rendered STL + preview PNG
    - mech/print/rover_assembly.scad: whole-rover 3D model; chassis.scad from CAD
    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
    [antenna_bobbin.stl, battery_tray.scad, battery_tray.stl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]
2026-06-08 Add stacked-deck chassis concept (decks + pillars + coil support)
    Alternative chassis: two rectangular decks with the EEEBug board's hole
    pattern, stacked on 4 corner pillars (either board on top), plus a braced
    coil ring + sensor perfboard tray that screws onto a deck. Each deck prints
    in two halves to fit the 200 mm printer. One STL per component.
    [coil_support.scad, coil_support.stl, deck.scad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]
2026-06-08 Fix: deck halves were rendered uncut (identical to full); add self-tap pillar
    - Re-rendered deck_half_A (front, 95x112) and deck_half_B (rear, 95x92) - the
    previous STLs were accidentally full decks (bad -D quoting in the render).
    - Pillar now has a Ø2.5 self-tap pilot + lead-in chamfers so short M3 screws
    fix it to the decks (was an unconnected clearance tube).
    [deck_half_A.stl, deck_half_B.stl, pillar.scad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]
2026-06-08 Add real seam join + joint diagrams (pillar + halves)
    - Deck halves now have SEAM_HOLES; splice bar has matching self-tap holes, so
    the two halves actually bolt together (the splice had nothing to fix to before).
    - Add corner_joint.scad + seam_joint.scad diagrams and exploded-view images
    showing how the pillars attach the decks and how the halves join.
    [corner_joint.scad, deck.scad, deck_full.stl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]
2026-06-08 Pillars 50mm (~5cm deck gap); add assembled seam view
    [pillar.scad, pillar.stl, stack_assembly.scad]
2026-06-08 Replace splice join with a direct half-lap OVERLAP between deck halves
    The two halves now overlap (front half = bottom ledge, rear half = top ledge)
    and clamp together with 2 M3 screws - no separate splice part. Removes
    splice.scad/stl; updates the seam diagrams to show the overlap.
    [deck.scad, deck_half_A.stl, deck_half_B.stl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]
2026-06-08 Fix: front pillar holes fell inside the motor-slot cut-outs; move to y=24 (solid material)
    [deck.scad, deck_full.stl, deck_half_A.stl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]
2026-06-08 Add to_print/ folder: the 4 printable STLs + PRINT_LIST.txt (quantities + instructions)
    [coil_support.stl, deck_half_A.stl, deck_half_B.stl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]
2026-06-08 to_print: drop coil_support (not printing it); now 3 files / 8 parts
    [coil_support.stl]
2026-06-08 to_print: add coil_support back (4 files / 9 parts)
    [coil_support.stl]
